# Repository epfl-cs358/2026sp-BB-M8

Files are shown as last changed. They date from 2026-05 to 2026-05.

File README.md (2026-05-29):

# 2026sp-BB-M8
<p align="center">
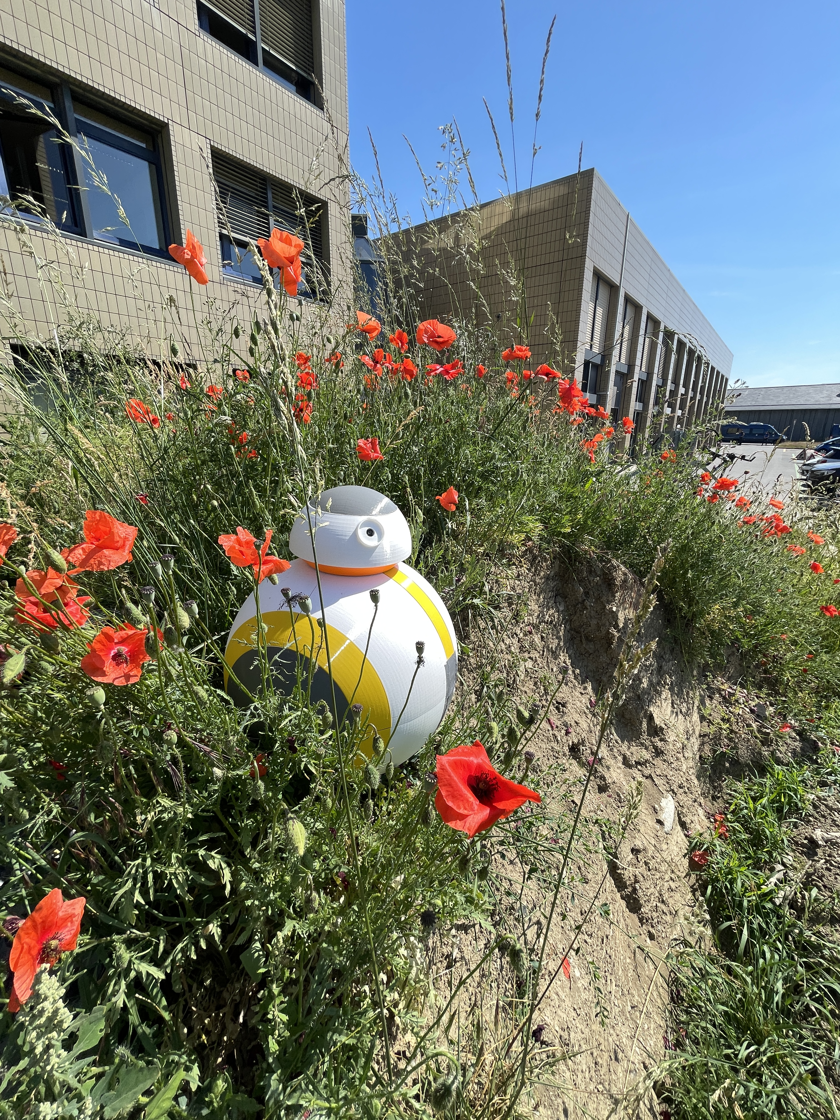
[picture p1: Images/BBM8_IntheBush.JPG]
  
</p>

## Contributors

* [Bernadette Orglmeister](https://github.com/boerniii)
* [Noa Cuccodoro](https://github.com/noa-ccdr)
* [Gaspard Héliot](https://github.com/gheliot)
* [Khadija Kammoun](https://github.com/khka5)
* [Gaël Diep](https://github.com/Damedane)
* [Jérôme Essola Elanga](https://github.com/Jess-lnga)

## Table of Content

- [2026sp-BB-M8](#2026sp-bb-m8)
  - [Contributors](#contributors)
  - [Table of Content](#table-of-content)
  - [Project overview](#project-overview)
    - [About the BB-M8](#about-the-bb-m8)
    - [List of Materials](#list-of-materials)
      - [Buy:](#buy)
      - [3D print:](#3d-print)
      - [Laser cut:](#laser-cut)
  - [Built the BB-M8](#built-the-bb-m8)
    - [Head](#head)
      - [Building the mechanical part:](#building-the-mechanical-part)
      - [Electronic Assembly of the head:](#electronic-assembly-of-the-head)
    - [Axis](#axis)
      - [Building the mechanical part:](#building-the-mechanical-part-1)
    - [Main Body](#main-body)
      - [Building the mechanical part:](#building-the-mechanical-part-2)
    - [Swinger](#swinger)
      - [Building the mechanical part:](#building-the-mechanical-part-3)
      - [Electronic Assembly of the swinger:](#electronic-assembly-of-the-swinger)
    - [Pole](#pole)
      - [Building the mechanical part:](#building-the-mechanical-part-4)
    - [Final assembly of the interior body](#final-assembly-of-the-interior-body)
      - [Building the mechanical part:](#building-the-mechanical-part-5)
      - [Electronic Assembly of the interior body:](#electronic-assembly-of-the-interior-body)
    - [Sphere](#sphere)
      - [Builting the sphere](#builting-the-sphere)
  - [Controlling the BB-M8](#controlling-the-bb-m8)
    - [Flashing the code](#flashing-the-code)
      - [Body (Wemos D1 R32 ESP32)](#body-wemos-d1-r32-esp32)
      - [Head (ESP32-CAM)](#head-esp32-cam)
      - [Uploading the dashboard (SPIFFS)](#uploading-the-dashboard-spiffs)
    - [Steering the BB-M8](#steering-the-bb-m8)
      - [Connecting](#connecting)
      - [Dashboard overview](#dashboard-overview)

## Project overview
### About the BB-M8
The BB-M8 is a spherical robot capable of moving across flat surfaces. This is achieved by means of an axis fitted with a pendulum, which can shift the centre of gravity, enabling the robot to navigate curves and maintain stability. The sphere also features a head, which is attached to the body by magnets and always remains on the upper surface of the sphere. The head is equipped with a camera and a rotating mechanism, allowing it to look in all directions. 

The BB-M8 can be connected to any computer via Wi-Fi and controlled from there via an interface, where you can also view the live feed from the camera.

Our BB-M8 is a replica of BB-8 from Star Wars.
The body has a diameter of approximately 35 cm, so a bit smaller than the original one.

### List of Materials
Here is an exhaustive list of all the elements needed to build the BB-M8. Note that you will need a 3D-printer with PETG filament to print some parts and a laser cutter.

#### Buy:
| Electronic Component | Model | Quantity |
|---|---|-----|
| Microcontroller | Wemos D1 R32 ESP32 | 1 |
| Microcontroller | AIThinker ESP32-CAM | 1 |
| Buck Converter | LM2596 | 2 |
| Stepper Motor | 28BYJ-48 | 1 |
| Motor Driver | ULN2003 | 1 |
| Servo Motor | DS3240 | 1 |
| Stepper Motor | NEMA 17 (17HS4401) | 1 |
| Motor Driver | TMC2208 | 1 |
| BMS 3S | HW-544 3S (11.1V/12.6V) BMS | 1 |
| BMS 2S | 2S 20A 18650 Lithium Battery Protection Board | 1 |
| LiPo | Conrad Energy 3S 11.1V 5000mAh | 1 |
| LiPo | LemonRC 2S 7.4V 350mAh | 1 |
| ON / OFF Switch | — | 2 | 
| Gearbox | 10:1 NEMA 17 gearbox | 1 |
| IMU | MPU-9250 | 1 |
| USB-to-TTL serial adapter | FTDI FT232R (HW-417-V1.2) | 1 |

| Other Parts | Specifications | Quantity |
|---|---|-----|
| Aluminium rod | 10 mm diameter, 310 mm length | 1 |
| Big Ball Bearings | 35 × 10 × 11 mm | 2 |
| Small Ball Bearing | 3 x 10 x 4 mm | 1 | <!-- TODO: What bearing is in the swinger -->
| Small Magnets | 5mm diameter, 4 mm height | 8 |
| Big Neodymium Magnets | 20 mm diameter, 12 mm height | 4 |
| Magnets for Bottom of Head | 14 mm diameter, 18 mm height | 4 |
| Wheels | 13 mm diameter | 4 |

- You will also need a **USB Isolator** to protect your computer and **data cables** to flash the code. 

- To charge the LiPos, you also need access to a **battery charging station**.
- Screws, nuts, heat-set inserts, jumpers and other basic supply is also needed, as well as tape and glue.

#### 3D print:
Here you can find all the [stl files](3D-Files/stl) that need to be printed with PETG filament. You find further information about the quantities in the specific subparts of building the BB-M8.

<!-- TODO: Uplode the stl file, and make a refernce to them -->

#### Laser cut:
The BB-M8 has also a few parts made of MDF. Here are the [dxf files](3D-Files/dxf). Note that you will need to use **different thicknesses** for the head and the body! Further information can be found in the corresponding section.
<!-- TODO: Uplode the dfx file, and make a refernce to them -->

## Built the BB-M8
Here are the instructions for building the BB-M8. Note that points having 🫟 in front of it, are further suggestions to make it cleaner and/or to remove unnecessary holes, for example, that are no longer needed.

Here you can find the [step file](3D-Files\FullAssembly.step) of the BB-M8.

### Head
<!-- TODO: Foto of the entire head -->
<!-- TODO: Describtion of the head and its functioning -->

https://github.com/user-attachments/assets/d43b33c3-5c80-41d6-bc25-aa63da8808fc

The head contains the ESP32-CAM with a camera and has an internal rotation mechanism, to make it turn. Another important aspect of the head is its iconic look and its size relative to the sphere, that makes our BB-M8 resemble the original one. 

<p align="center">
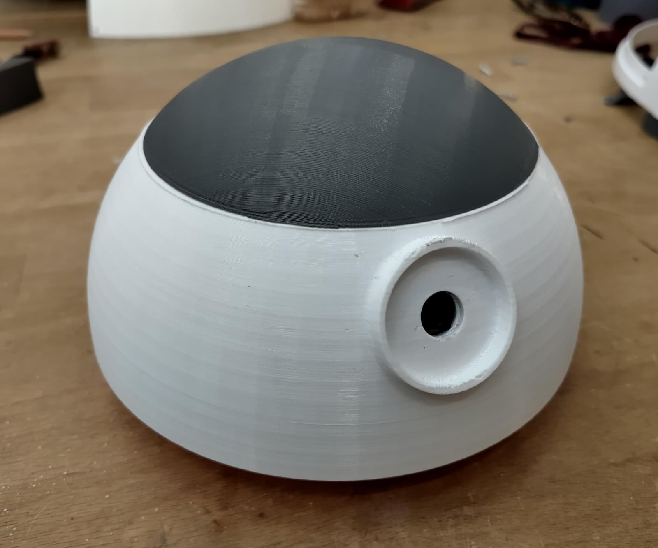
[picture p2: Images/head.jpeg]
  
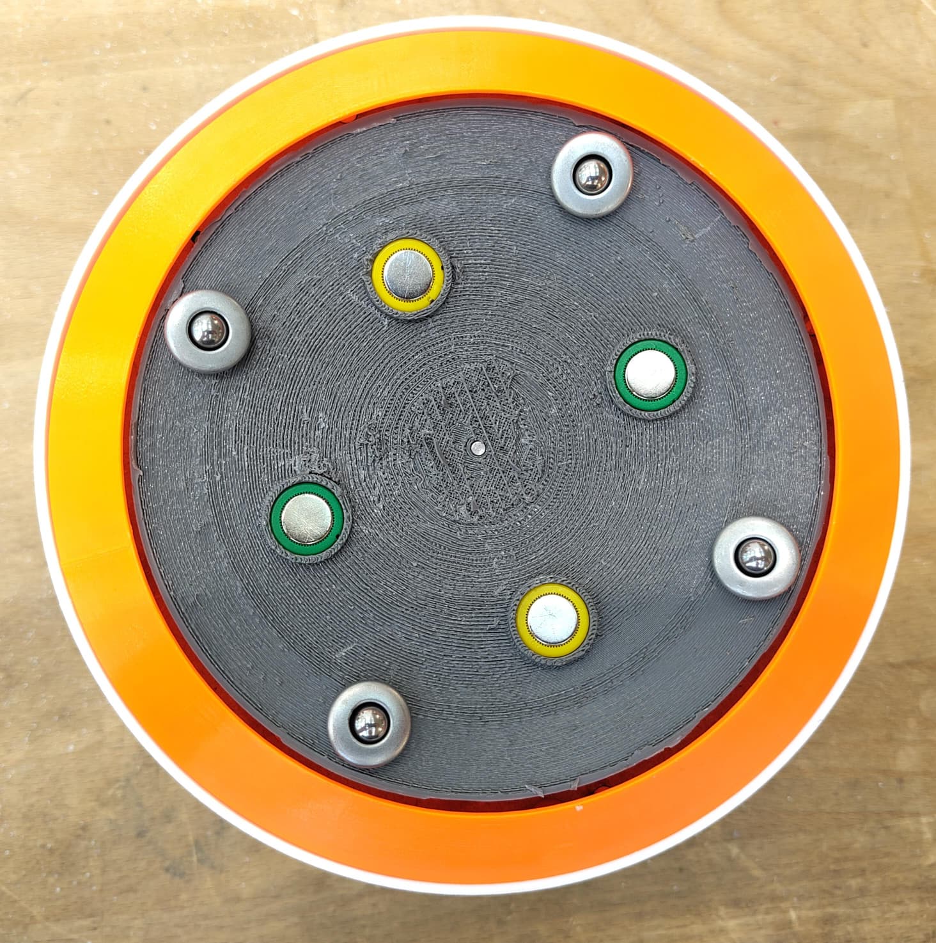
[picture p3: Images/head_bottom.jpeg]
  
</p>

#### Building the mechanical part:
The head is divided into different elements: the lid, the bottom plate (holding the magnets), the top plate (where the components are attached) and the manchette (hiding the bottom plate). 

1. Bottom plate:
    - Print the [bottom Plate](3D-Files/stl/Head_BottomPlate.stl) with PETG filament.
    - Add the **three heat-set inserts**.
    - Screw the [gear](3D-Files/stl/Head_GearBottomPlate.stl) to it.
    - Put the magnets and the wheels into the holes.
    - 🫟 The bottom plate and the gear can be printed in one piece. 

2. Lid: 
    - Print the [bottom of the lid](3D-Files/stl/Head_BottomPartLid.stl) and two times the [top of the lid](3D-Files/stl/Head_TopPartLid.stl).
    - Screw the two top parts together.
    - Then screw it to the rest of the lid.
    - Glue the small magnets into the holes. 
    - 🫟 The holes where the top is connected to the bottom do not perfectly line up, so if you want to have it more beautiful, change it.
    - 🫟 Theoretically, the lid could be printed in one piece with the front side of the ESP32 Holder directly attached to it. 

3. ESP32 Holder:
    - Print the two parts of the ESP32 Holder, [front](3D-Files/stl/Head_ESP32HolderFrontSide.stl) and [back](3D-Files/stl/Head_ESP32HolderBackSide.stl).
    - Add three heat-set inserts into the holes.
    - Then glue it into the lid, so that the holes for the camera line up.
     
4. Top Plate:
    - Laser cut the [top plate](3D-Files/dfx/Head_TopPlate.dxf) with the [stepper holder](3D-Files/dfx/Head_TopPlateStepper.dxf) and two times its [side](3D-Files/dfx/Head_TopPlateSides.dxf) using **4mm MDF**.
    - Glue the parts together.
    - Glue small magnets into the four holes at the edge.
    - Glue a small ball bearing into the hole in the middle, **pay attention that no glue drips into the bearing!**
    - Once the [electronic assembly](#electronic-assembly-of-the-head) is done, screw it onto the plate.
        - Make sure that the screws don't interfere with the magnets and wheels of the bottom plate.
        - Before attaching the stepper, make sure to print and add the [gear](3D-Files/stl/Head_GearForStepper.stl) and also depending on the size of the screw head, carve the edges so that they are not in the way of the gear.
    - Add a bit of velcro to the LiPo and the counterpart to the plate.

5. Final Assembly:
    - Print and then glue the [ball bearing stopper](3D-Files/stl/Head_BallBearingStopper.stl) to a small rod (that fits the ball bearing perfectly). Then slide it through the ball bearing and into the gear of the bottom plate, line it up with the other gear and then attach it with a screw. 
    - 🫟 The attachment of the bearing can be done more properly by using rings and creating a shaft. <!-- TODO: Better explenation -->

6. Manchette:
    - Print the [manchette](3D-Files/stl/Head_Manchette.stl)
    - Add four M2.5 heat-set inserts into the four holes.
    - Screw it to the top plate.

Now the head can be easily opened and closed with the magnets!

<p align="center">
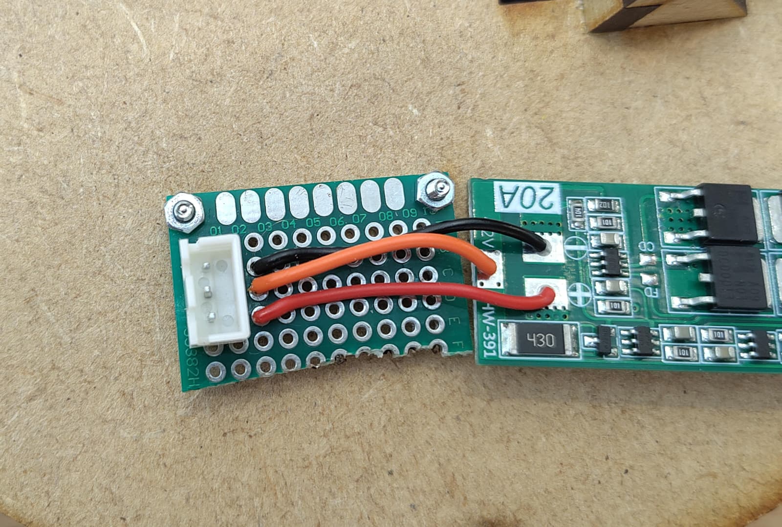
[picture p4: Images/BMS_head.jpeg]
    
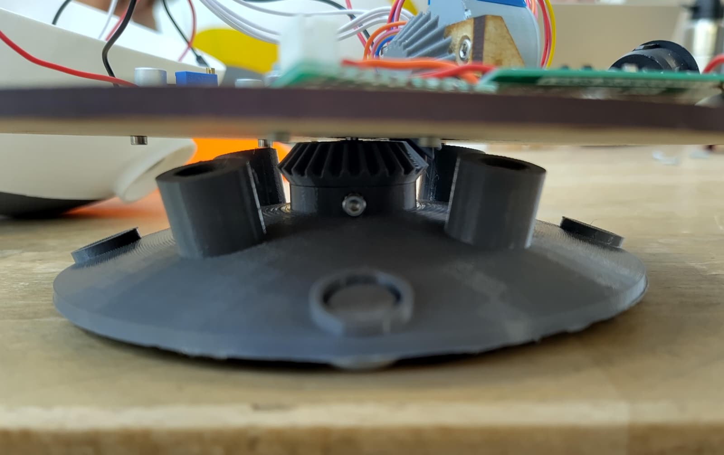
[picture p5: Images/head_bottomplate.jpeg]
    
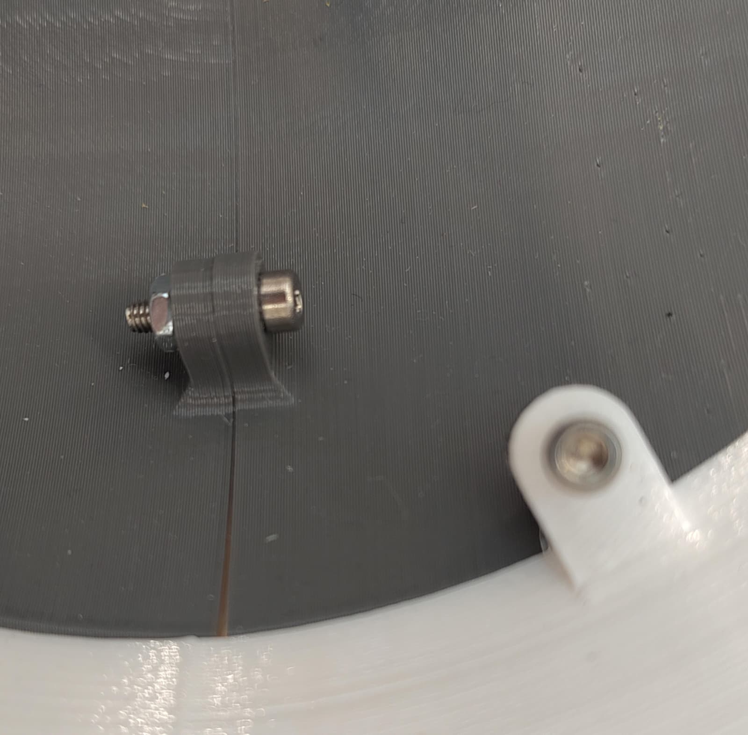
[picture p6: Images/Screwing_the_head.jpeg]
    
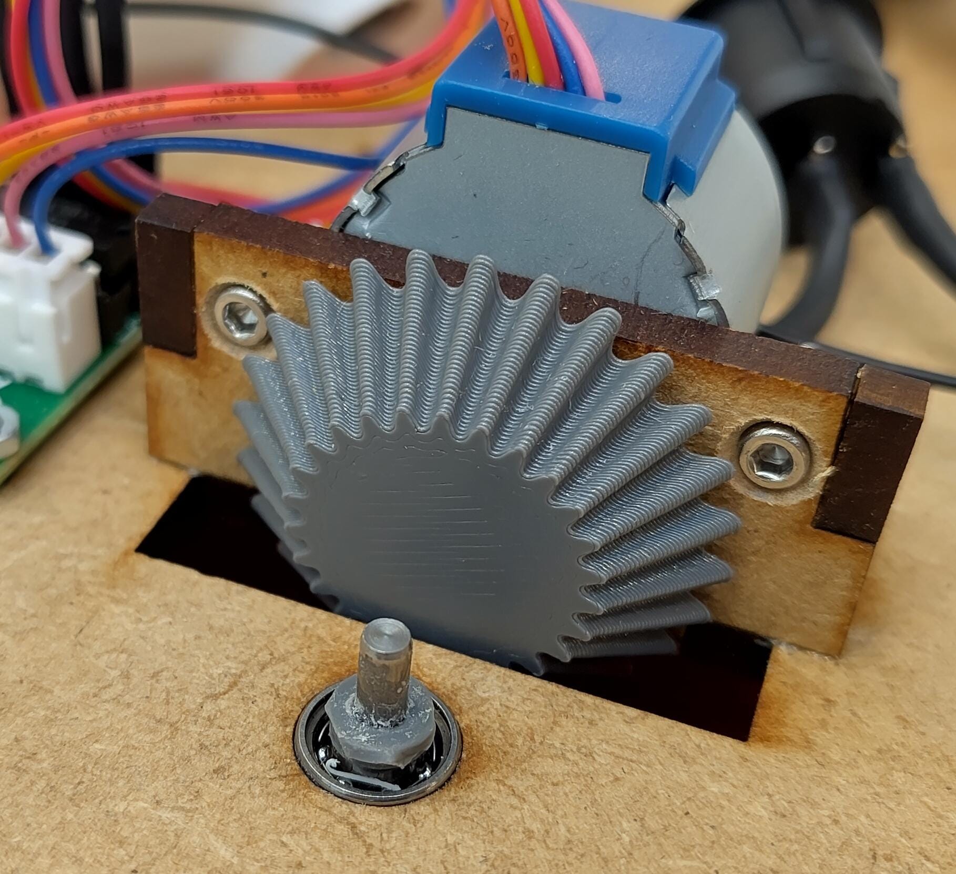
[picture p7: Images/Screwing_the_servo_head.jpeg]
    
</p>

<p align="center">
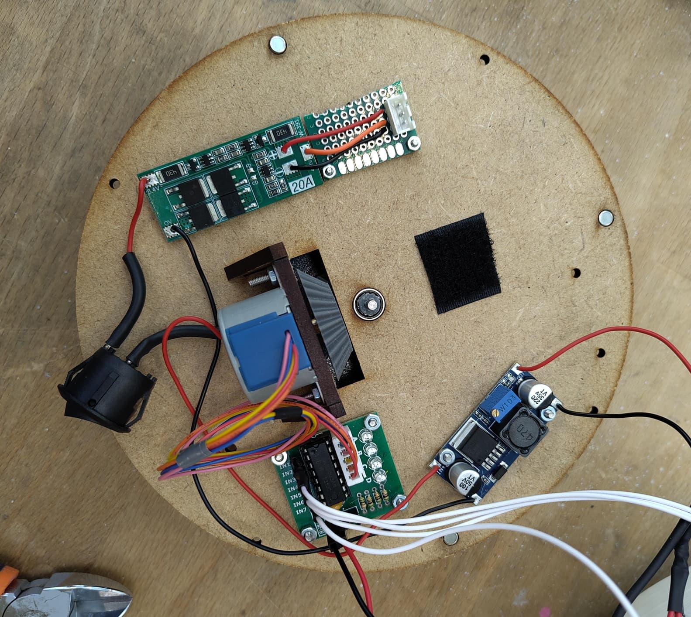
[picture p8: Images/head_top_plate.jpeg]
    
    <!-- TODO: Image of the inside of the lid with EPS32 CAM-->
</p>

<!-- TODO: Continue-->

#### Electronic Assembly of the head:

<p align="center">
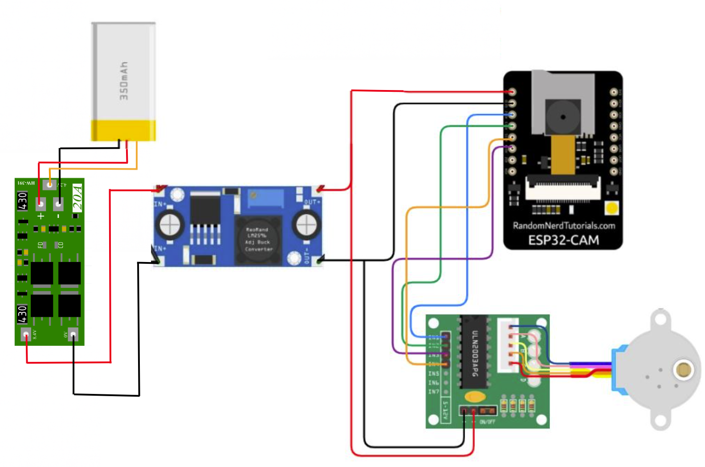
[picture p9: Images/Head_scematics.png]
    
</p>

1. Calibrate the **buck converter to 5V**.
2. Solder the connector of the LiPo to the BMS and make sure that it works correctly.
3. Connect the components as in the schematic above. 
    - Make sure that the **cables connecting the ESP32-CAM are long** enough to easily open the lid of the head. 

### Axis
The Axis is the part that will transmit the rotation from the stepper to the sphere. It is made of aluminium to make sure it doesn't bend, it also holds a gear that should be making the axis turn, 2 bearings that will hold the main body and avoid friction, 4 stop rings that will make sure the bearings stay in place, and the box doesn't slip out of the bearing, and finally a junction in 2 parts that will be the attachment of the axis to the body.  

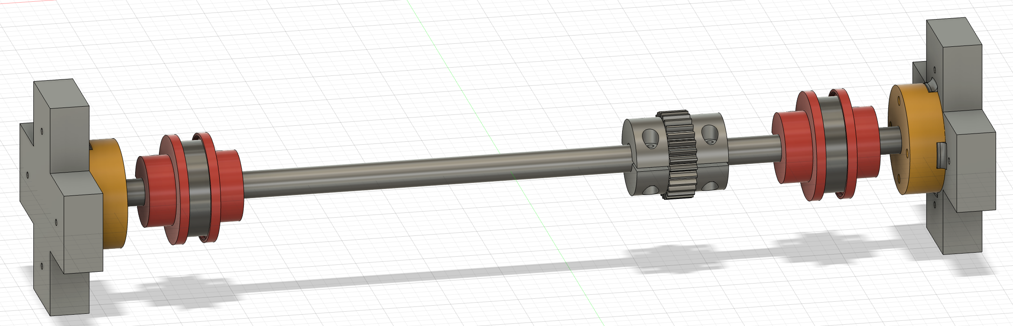
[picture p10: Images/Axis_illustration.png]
Axis Illustration


https://github.com/user-attachments/assets/9146e50d-00f2-4c6c-8933-5cecaacd3a80

#### Building the mechanical part:
The axis is divided into different elements: the rod, the gear, the bearings, the stop rings, the first junction, and the second junction. 

1. Rod:
    - Get yourself a 310mm aluminium rod with diameter 10.
    - Drill holes and thread them with a lathe at the two ends of the rod for M2.5 Screws. The holes should be around 5mm deep.
    - Make a 10mm D shape that is 1mm deep at the 2 ends, and make sure the 2 ends have D shapes facing the exact same direction.
    - 🫟 The deepness of the holes, and the length of the D shapes can be a bit bigger and it will totally work. Just don't make them smaller.
    - 🫟 If you need visual support, [here](3D-Files/stl/Axis_Rode.stl) is an STL file, but DO NOT PRINT IT, it won't be resistant enough!  

2. Gear: 
    - 3D Print the [gear](3D-Files/stl/Axis_GearMainPart.stl) and two times the [second part of the gear](3D-Files/stl/Axis_GearSecondPart.stl).
    - Add 4 M2.5 heat-set inserts.
    - With 4 M2.5x16 screws and 4 M2.5 nuts, tighten the gear around the axis.
    - 🫟 For now do not tighten them to the max so that you can easily move it around and find the right position once the main body is done.
    - 🫟 Keep in mind that all the axis will have to be disassembled and reassembled into the actual main body, so this is just to test and make sure all parts work.

3. Bearings:
    - Buy two bearings of size 35x10x11.
    - You'll put them on the rod on each side after adding the two first stop rings (next step).
     
4. Stop rings:
    - 3D print 4 times the [stop rings](3D-Files/stl/Axis_StopRing.stl).
    - Add 4 M2.5 heat-set inserts.
    - With 4 M2.5x16 screws and 4 M2.5 nuts, tighten the stop rings around the axis.
    - Remember to follow the first screenshot to put everything in the right order.

5. First junction:
    - 3D print 2 times the [first junction](3D-Files/stl/Axis_JunctionWithSphere.stl).
    - Put it in the D shape of each end, and screw it to the rod with an M2.5x10.
    - 🫟 If you cannot find a screw that perfectly tightens the junction, just add nuts until it has the desired length (and vary the length of the screw). 

6. Second junction:
    - 3D print 2 times the [second junction](3D-Files/stl/Axis_JunctionToJunction.stl).
    - Just clip it on the first junction.

Now the Axis is done, you'll have to disassemble it and reassemble it in the main body once you're sure each component of the axis is well made!

### Main Body
The main body is essentially a wooden box with a few holes to put a Servo, and has the important duty to hold the axis, the NEMA, the pole for the head, and the swinger. It is the centrepiece of the project.  
<p align="center">
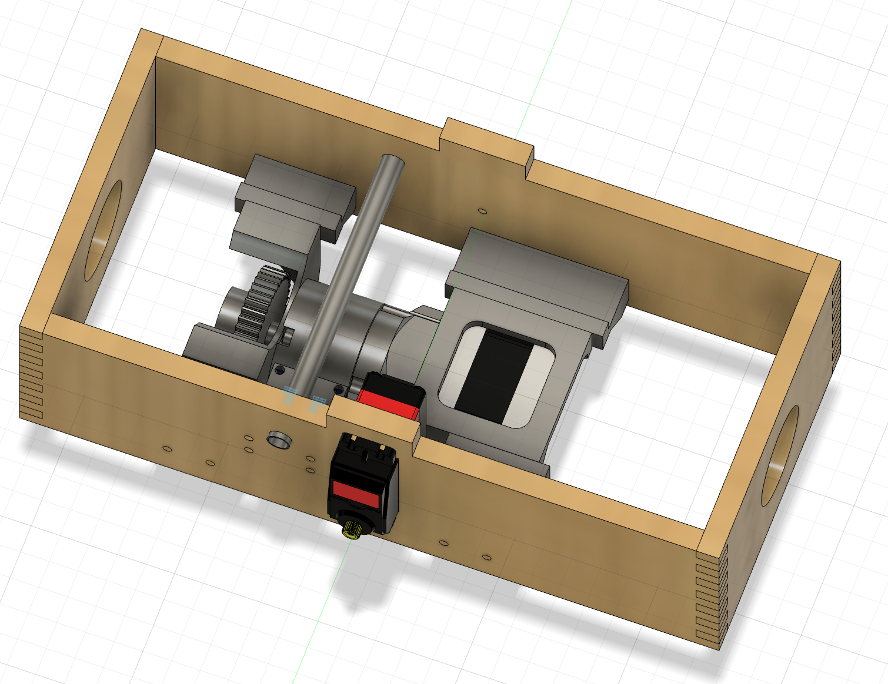
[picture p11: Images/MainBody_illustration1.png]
    
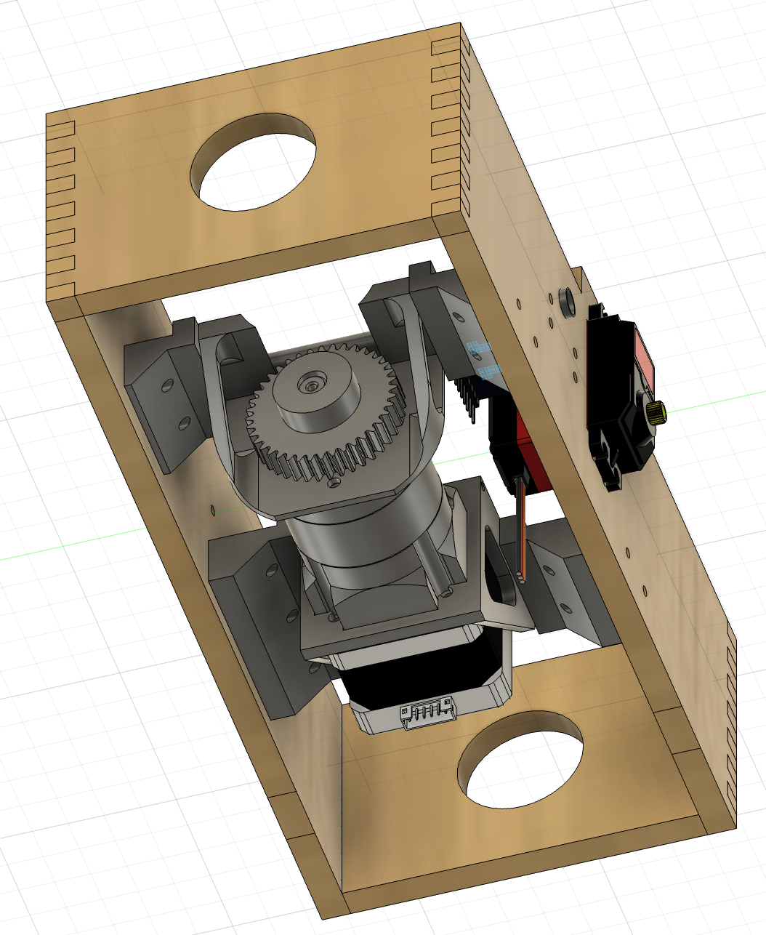
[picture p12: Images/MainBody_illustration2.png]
    
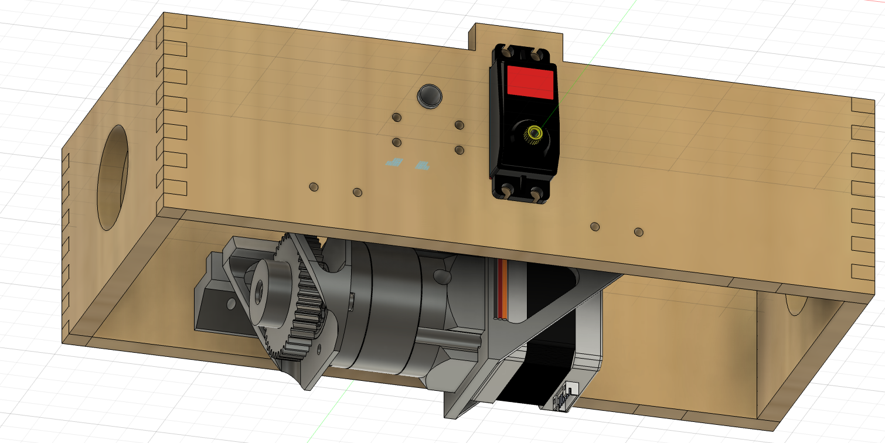
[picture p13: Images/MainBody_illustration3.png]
    
</p>

https://github.com/user-attachments/assets/4a70eb73-42a0-409a-afb2-720c48bfd937

#### Building the mechanical part:
The main body is divided into multiple parts: the box, the IMU holder, the two NEMA holders, the stepper and its gearbox, the gear on the gearbox shaft, the Servo, and the pin that holds the second arm of the swinger.

1. Box:
    - On an 8mm thickness sheet of MDF, laser cut one [Large side](3D-Files/dxf/SideBoxLarge.dxf), one [Large side with servo](3D-Files/dxf/SideBoxLargeServoHole.dxf), and two [Sides with holes for axis](3D-Files/dxf/SideBoxWithHoleForAxis.dxf).
    - Then be careful to glue everything together with 90° angles (easier said than done!).

2. IMU holder: 
    - 3D print the [IMU holder](3D-Files/stl/MainBody_IMUHolder.stl).
    - Put it into place with 2 M3x10 screws and 2 M3 nuts. 

3. NEMA holders:
    - 3D print one [NEMA holder Servo side back](3D-Files/stl/MainBody_NemaHolderAttachementServoSide.stl), one [NEMA holder Cap side back](3D-Files/stl/MainBody_NemaHolderAttachementCapSide.stl) and one [NEMA holder](3D-Files/stl/MainBody_NemaHolder.stl). All of these three will attach the NEMA to the center of the box. First assemble this.
    - Then the next three parts are going to prevent the NEMA's shaft from bending and losing the contact between the two gears.
    - 3D print two [NEMA holder front](3D-Files/stl/MainBody_NemaHolderShaft.stl) and one [NEMA holder front screwed](3D-Files/stl/MainBody_NemaHolderScrewed.stl). Assemble these last three pieces together. 
     
4. Stepper & Gearbox:
    - Assemble the NEMA 17 with the Gearbox, and make sure the NEMA Shaft is tightened on the gearbox input.
    - Assemble the NEMA 17 with the NEMA holders using 9 M2.5x10 for the holders themselves, and 9 M3x12 to connect the holders on the MDF box.
    - 🫟 Make sure the socket of the NEMA is looking down.
  
5. Gear shaft:
    - 3D print this [gear](3D-Files/stl/MainBody_GearShaft.stl), make sure you put at least 90% infill to avoid an embarrassing breaking of the gear.
    - Put the gear on the shaft of the gearbox and screw an M3x16 screw with an M3 nut that you're going to fit in the hole extruded for it.

6. Servo:
    - Add the Servo in its hole. Make sure its cables are looking down. 
    - Screw it with 4 M3x12 screws and 4 M3 nuts.  

7. Pin:
    - Buy a pin that is 3mm diameter and 40mm long.
    - Put it inside the hole that is facing the Servo on the opposite side of the box.
    - 🫟 This pin will hold the second arm of the Swinger. 

Now the Main Body is done, let's build the Swinger!

### Swinger
The Swinger is a very technical part; it'll hold all the electronics, and swing thanks to the Servo to make the BB-M8 turn and balance. 

<p align="center">
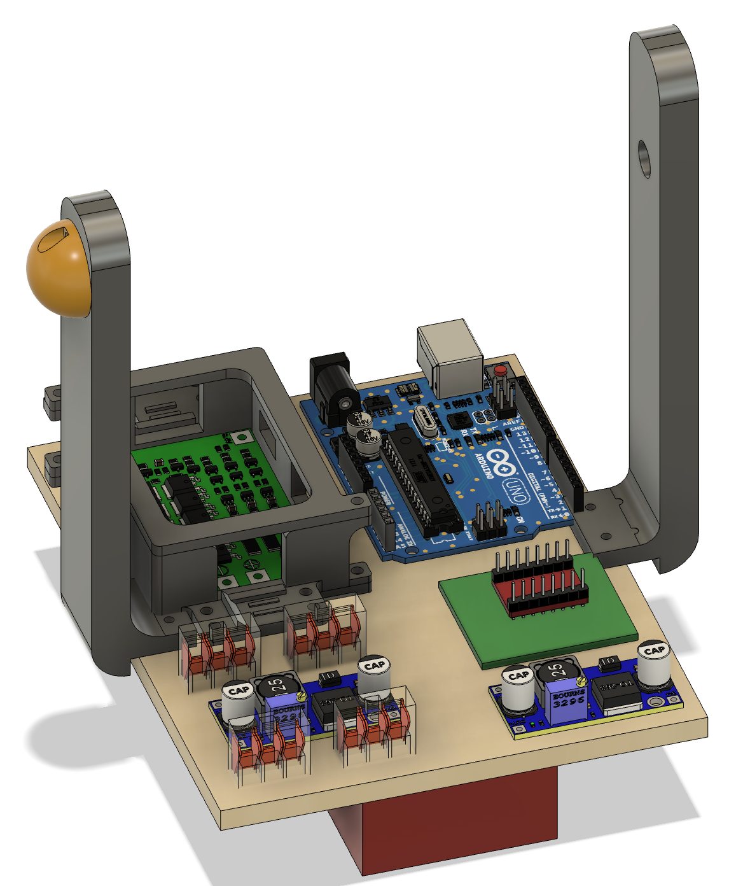
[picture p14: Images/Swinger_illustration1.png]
    
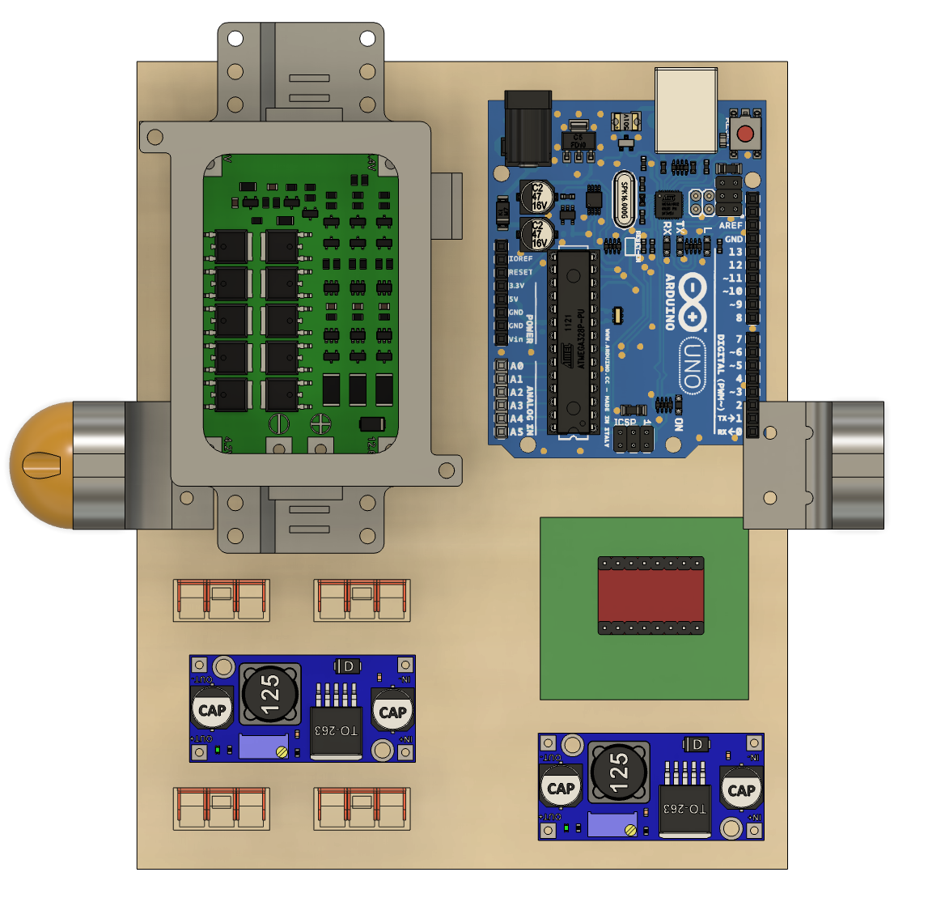
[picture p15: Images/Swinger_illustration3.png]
    
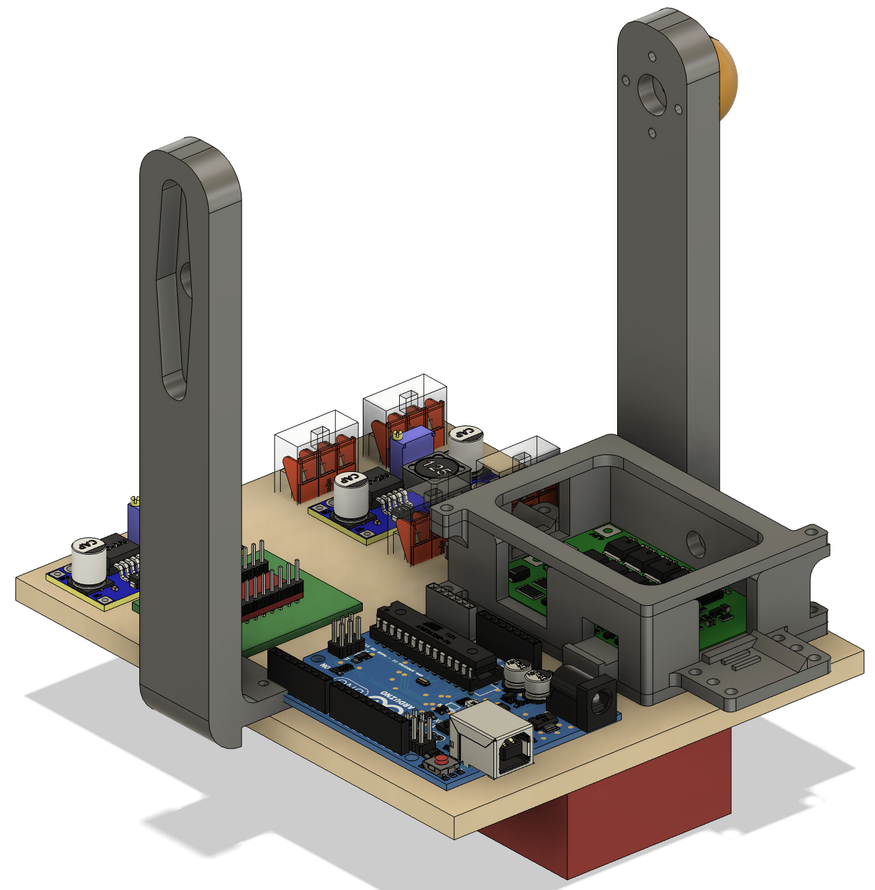
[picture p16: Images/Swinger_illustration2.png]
    
</p>

https://github.com/user-attachments/assets/8d093857-c81f-4bc1-969b-20ae95724053

#### Building the mechanical part:
The Swinger is essentially a rectangular MDF sheet with holes to screw all the electronics, velcro under to stick the LiPo, and arms to connect to the main body. It will hold the BMS inside a BMS box, the 2 buck converters, the ESP32, the NEMA's driver, and some wago.

1. MDF Sheet
   - On a 6mm MDF plate, Laser cut this [sheet](3D-Files/dxf/Swinger_Sheet.dxf).
2. BMS Box
   - 3D print the [BMS Box](3D-Files/stl/Swinger_BMSBoxBox.stl) and its [Bottom](3D-Files/stl/Swinger_BMSBoxBottom.stl).
   - After soldering the cables and connectors, put the BMS inside the Box, and screw the box and bottom to the MDF sheet with 2 M2.5x10 screws.
3. Arms
   - 3D print the [Servo arm](3D-Files/stl/Swinger_ArmServo.stl) and the [Cap arm](3D-Files/stl/Swinger_ArmBearing.stl).
   - In the servo arm, put the Servo horn that fits the extruded shape.
   - In the Cap arm, add a 10x3x4 bearing in the extruded cylinder shape.
   - Screw the 2 arms with 2 M2.5x12 and 2 M2.5 nuts for each arm on the sheet of MDF.
4. Cap 
   - 3D print the [Cap](3D-Files/stl/Swinger_ArmCap.stl).
   - Screw it with 2 M2.5x12 and 2 M2.5 nuts on the Cap arm.
5. LiPo
   - Put some velcro under the Swinger and on the LiPo to make them stick. 
6. Weight
   - Add the weight around the LiPo by hot-gluing it.
7. Electronic components
   - Add all the electronic components on the MDF sheet and make sure they are well screwed.
   - 🫟 Remember that the LiPo is right under the electronic components, therefore, there shouldn't be any screws sticking too much out to avoid damaging the LiPo.

#### Electronic Assembly of the swinger:
<p align="center">
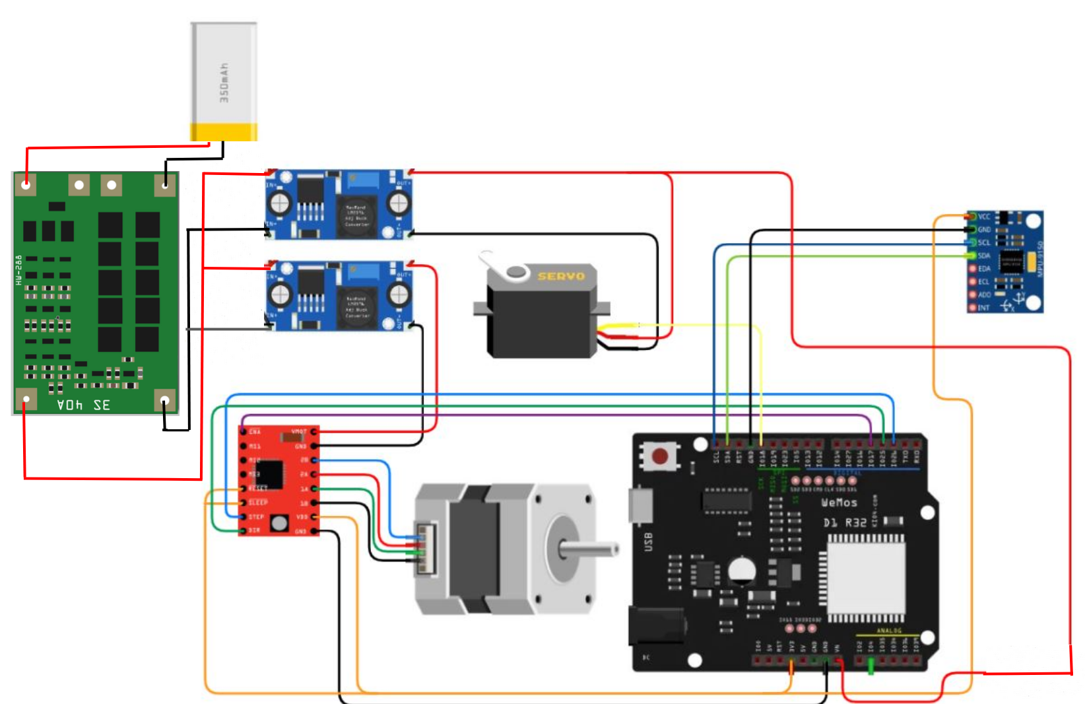
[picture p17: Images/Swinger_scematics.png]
    
   </p>

The swinger hosts all the body electronics. Connect the components as follows:

1. **Power distribution:**
    - The LiPo (3S 11.1V) connects to the BMS, then through the ON/OFF switch to the rest of the circuit.
    - **Buck converter 1** (set to **6V**) → servo DS3240 only.
    - **Buck converter 2** (set to **5V**) → Wemos D1 R32 + TMC2208 driver + IMU.
    - Keeping the servo on its own buck converter prevents it from stealing current from the ESP32 when it moves.

2. **Wemos D1 R32:**
    - Connect the TMC2208 STEP and DIR pins to the dedicated GPIO pins (GPIO 25 and GPIO 26).
    - Connect the servo signal wire to GPIO 18.
    - Connect the IMU (MPU-9250) via I²C: SDA → GPIO 21, SCL → GPIO 22.

3. **NEMA 17:**
    - Connect the four motor wires to the TMC2208 driver outputs.

> Make sure the GND of all components is shared, even across the two buck converters, otherwise the servo PWM signal will not work correctly.

### Pole
The pole is the part that sticks from the main body to hold magnets that will attach the head. 

#### Building the mechanical part:
The pole is divided into three elements: the body attachment, the pole and the magnets holder.

1. Body attachment
   - 3D print the [body attachment](3D-Files/stl/Poll_BodyAttachement.stl), and put an M2.5 heat-set insert inside the hole.
   - Add an M2.5x12 screw.
2. Pole 
   - Cut a 20mm diameter pipe to 135mm (use a pipe type, not a solid rod, the goal is to avoid putting too much weight high up).
3. Magnets holder
   - 3D print the [magnets holder](3D-Files/stl/Poll_MagnetHolder.stl), put an M2.5 heat-set insert inside the hole, then add the M2.5x12 screw.
   - Put the magnets inside, then tape them, and put some hot glue on the back to avoid having the magnets escaping.

### Final assembly of the interior body
Now that you've successfully built each part of the interior of the body successfully, it's time to assemble them.

#### Building the mechanical part:
1. Axis & Main body 
   - Slide the Axis into the Main body, and, when half way sliding it, add all the components of the axis that will be inside the box.
   - It may be slightly difficult to correctly align the two gears, but it is perfectly normal.
   - Make sure to tighten all the screws very well (without breaking the inserts).
<p align="center">
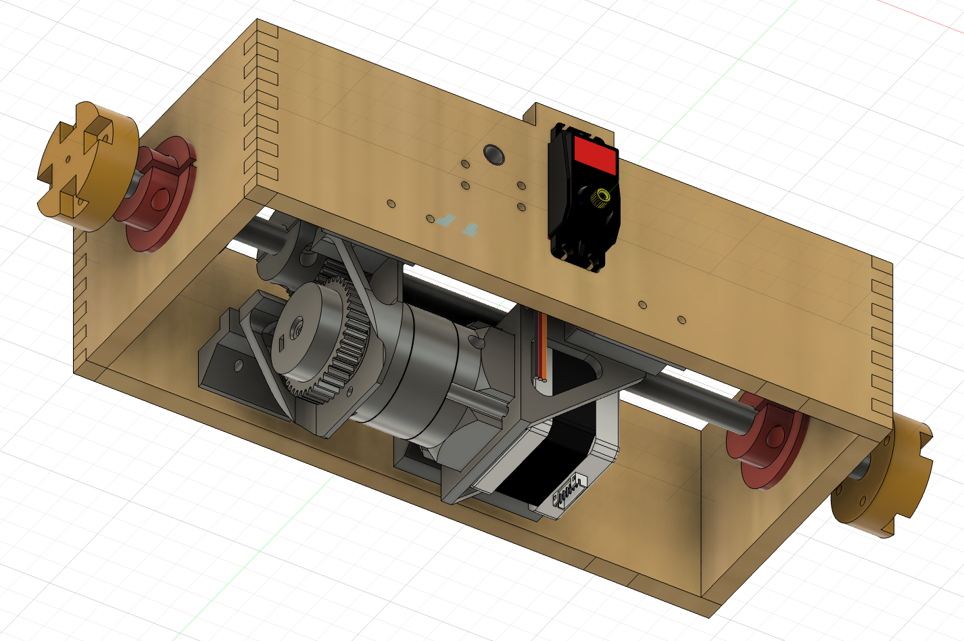
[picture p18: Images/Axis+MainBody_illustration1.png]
    
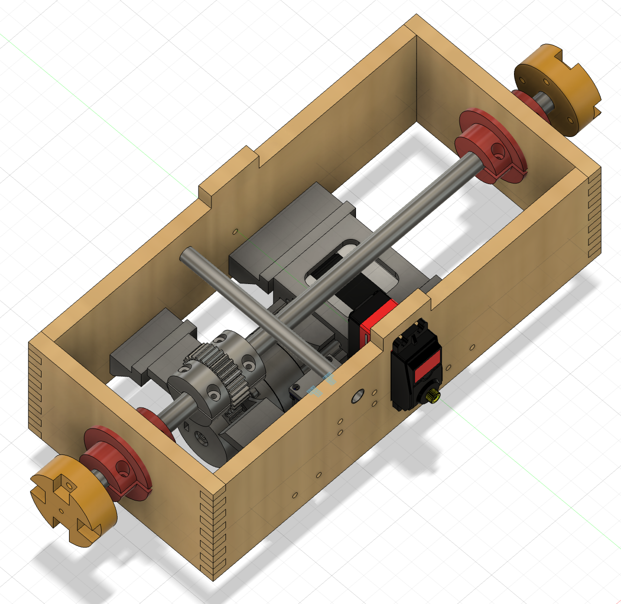
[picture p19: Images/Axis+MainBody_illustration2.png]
    
</p>
2. Pole
   - Screw the whole pole part to the main body with 4 M2.5x12 screws and 4 M2.5 nuts.
3. Swinger 
   - Connect now the swinger with the rest by clipping the Servo into its horn, and secure it with its screw, and on the other side, slide the pin through the arm cap, and through its bearing.
<p align="center">
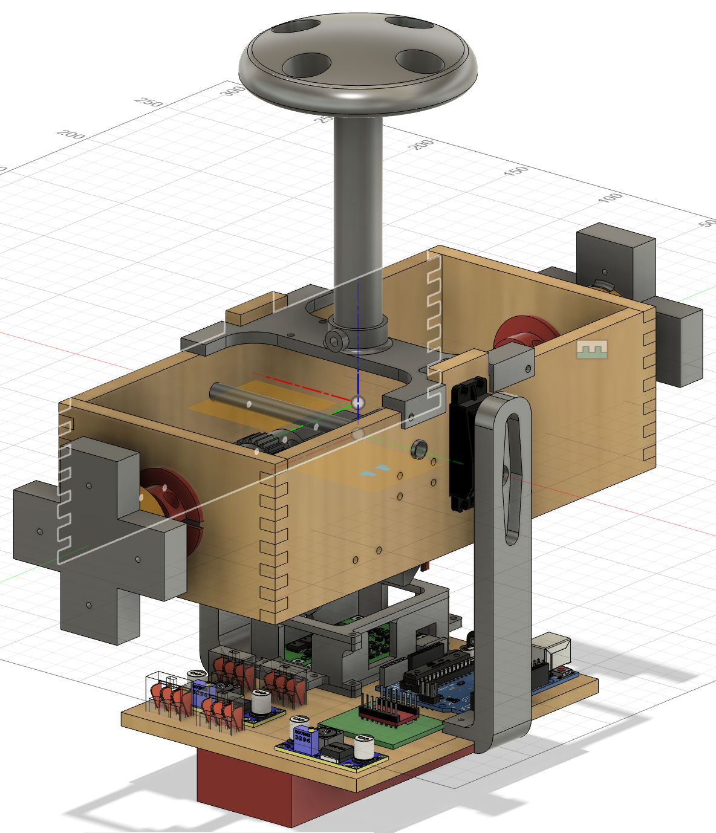
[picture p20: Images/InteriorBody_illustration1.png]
    
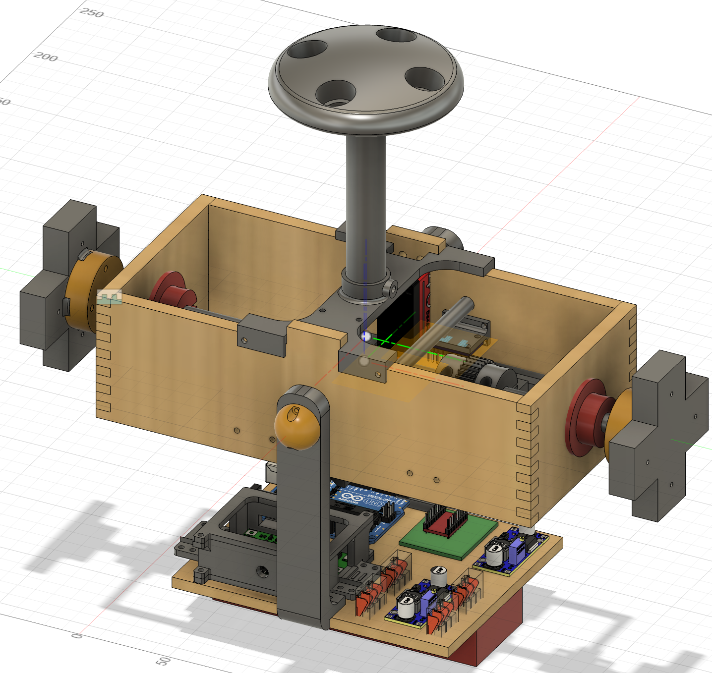
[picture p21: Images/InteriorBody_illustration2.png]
    
</p>

#### Electronic Assembly of the interior body:
1. Servo 
   - Connect the Servo to its dedicated wires.
2. IMU
   - Connect the IMU to its dedicated wires.
3. NEMA
   - Connect the NEMA to its dedicated wires.
4. Cable management
   - Make sure the electronics in the swinger doesn't touch the gear on the shaft of the gearbox at any position of the swinger  

You now have the whole interior body. All that's left is to put it inside the sphere, and... voilà!

### Sphere

https://github.com/user-attachments/assets/a65b6fe3-ab26-49d3-bca7-5c9b17b3753b

The sphere itself is 3D-printed in multiple smaller parts so that it can easily be printed on a normal sized Prusa. You need to print the following parts in PETG filament:

| stl file | Quantity |
|---|---|
| [caps](3D-Files/stl/Sphere_Cap.stl) | 2 |
| [bones](3D-Files/stl/Sphere-Bone.stl) | 8 |
| [equator piece](3D-Files/stl/Sphere_Equator.stl)| 4 |
| [top yellow piece](3D-Files/stl/Sphere-TopYellowPart.stl) | 8 |
| [white parts](3D-Files/stl/Sphere_WhitePart.stl) | 6 |
| [opening lid](3D-Files/stl/Sphere_Lid.stl) | 2 |
| [lid surrounding](3D-Files/stl/Sphere_LidSurrounding.stl) | 2 | 

#### Builting the sphere
 1. 3D-Print all the parts.
 2. Glue the pieces together with hot glue.
    - It is important to keep **1/4 open** so that the inner body still can be placed inside.
    - **Do not** glue the caps to the rest of the sphere. 
 
3. Place the [main body](#main-body) inside and make sure that it has enough space.
4. Put the second cap on top, close the last part and attach it with tape.

<p align="center">
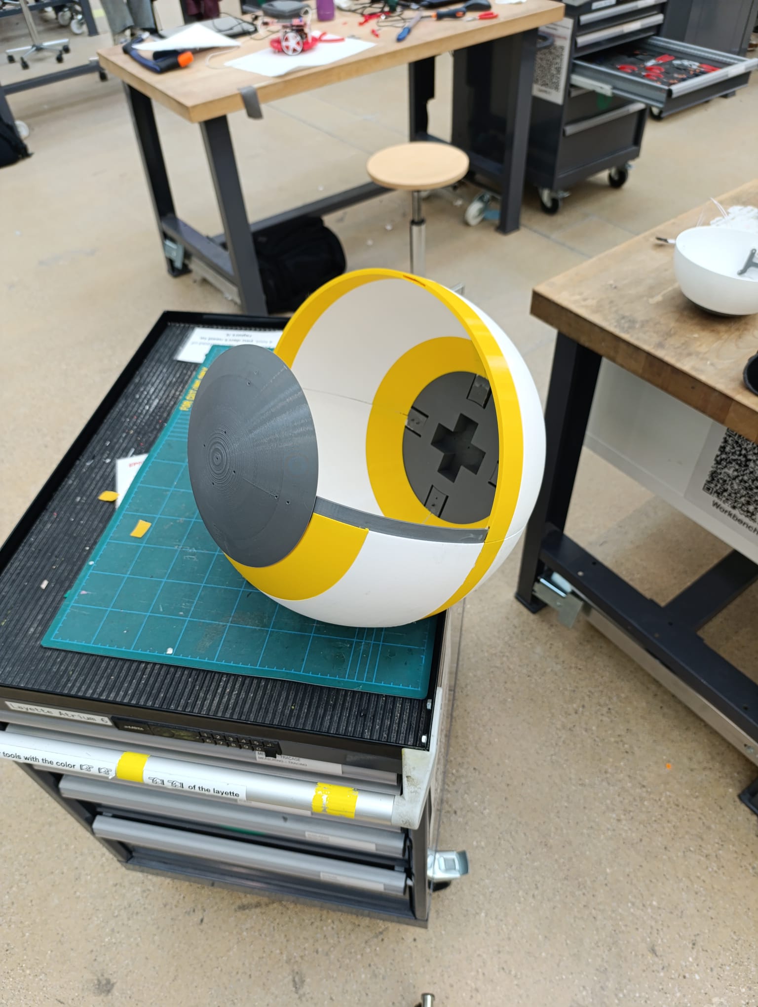
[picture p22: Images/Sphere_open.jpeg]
    
</p>

## Controlling the BB-M8

### Flashing the code

You will need [PlatformIO](https://platformio.org/) installed in VS Code to flash both microcontrollers.

#### Body (Wemos D1 R32 ESP32)

The Wemos has a native USB port — no adapter needed.

1. Connect the Wemos to your computer via USB.
2. Open the `BBM8_body` folder in VS Code with PlatformIO.
3. Click **Upload** or run `pio run --target upload` in the terminal.

#### Head (ESP32-CAM)

The ESP32-CAM has no native USB port. You need a **FTDI FT232R USB-to-TTL adapter** to flash it.

**Wiring (FTDI → ESP32-CAM):**

| FTDI | ESP32-CAM |
|---|---|
| TX | U0R (RX)  |
| RX | U0T (TX)  |
| 5V | 5V |
| GND  | GND |

Also connect **IO0 → GND** on the ESP32-CAM to enable flash mode. **Remove this wire after flashing.**

1. Wire the FTDI to the ESP32-CAM as above.
2. Open the `BBM8_head` folder in VS Code with PlatformIO.
3. Click **Upload**. When you see `Connecting......` in the terminal, press the **RST** button on the ESP32-CAM.
4. Once the upload is complete, disconnect IO0 from GND and press RST again.

#### Uploading the dashboard (SPIFFS)

The web dashboard (`BBM8_head/data/index.html`) is stored on the ESP32-CAM's filesystem and must be uploaded separately from the code.

1. Keep the FTDI connected.
2. In VS Code with PlatformIO, run **Platform → Upload Filesystem Image**, or run `pio run --target uploadfs` in the terminal.
3. The dashboard will now be served at `http://192.168.4.1` every time the head powers on.

---

### Steering the BB-M8

#### Connecting

1. Power on the BB-M8.
2. On your computer or phone, connect to the Wi-Fi network **`BBM8`** (password: `starwars`).
3. Open a browser and navigate to **`http://192.168.4.1`**.

#### Dashboard overview

**Camera feed**
Click **FEED ON** in the top-right corner of the camera panel to start the live FPV stream.

**Movement**
Use the **virtual joystick** to drive BB-M8 — the Y axis controls forward/backward speed, the X axis controls steering. The **arrow keys** on your keyboard work as well.

**Telemetry**
The bottom panel shows 7 live graphs updated at 10 Hz: Roll, Pitch, Drive Speed, PID Output, PID Error, Integral and Derivative.

**PID tuning**
Adjust Kp, Ki, Kd in the right panel and click **Apply Gains** to send them to the robot without reflashing. Starting values: Kp = 0.9, Ki = 0.05, Kd = 0.1.

**Target Roll / Target Speed**
Send a fixed value directly to the robot independently of the joystick. Useful for calibration.

**Safety**
The **STOP** button immediately halts the robot. Click **RESUME** to re-enable.　The robot starts in STOPPED mode for safety reasons.

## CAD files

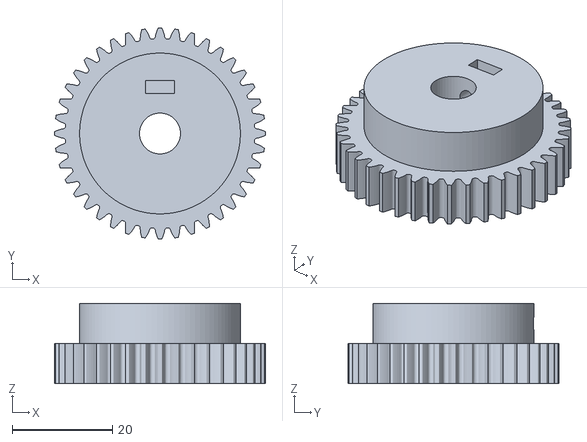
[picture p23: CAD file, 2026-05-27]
3D-Files/stl/MainBody_GearShaft.stl
42.0 x 42.0 x 16.0

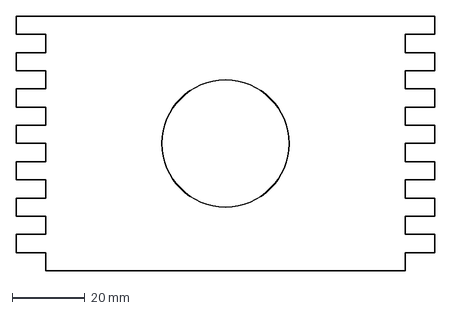
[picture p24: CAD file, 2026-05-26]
3D-Files/dxf/MainBody_SideBoxWithHoleForAxis.dxf
115.0 x 70.0 mm

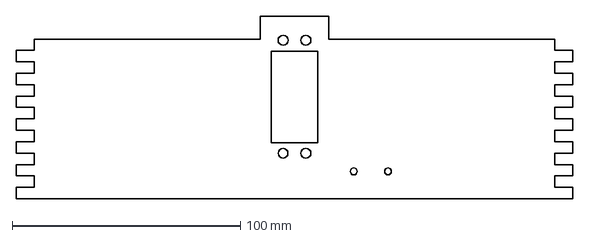
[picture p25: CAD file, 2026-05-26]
3D-Files/dxf/MainBody_SideBoxLargeServoHole.dxf
244.0 x 80.0 mm

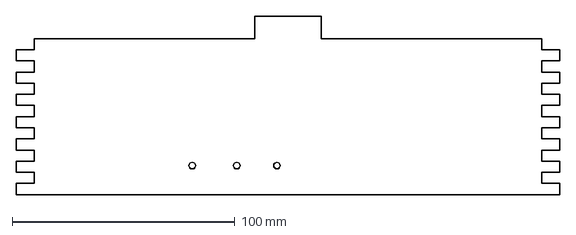
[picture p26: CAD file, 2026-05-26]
3D-Files/dxf/MainBody_SideBoxLarge.dxf
244.0 x 80.0 mm

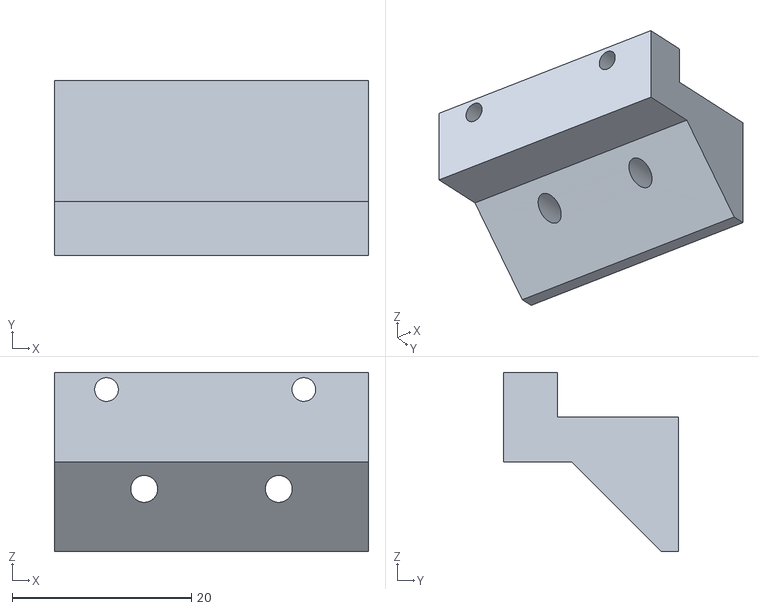
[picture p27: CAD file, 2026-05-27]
3D-Files/stl/MainBody_NemaHolderShaft.stl
35.0 x 19.5 x 20.0

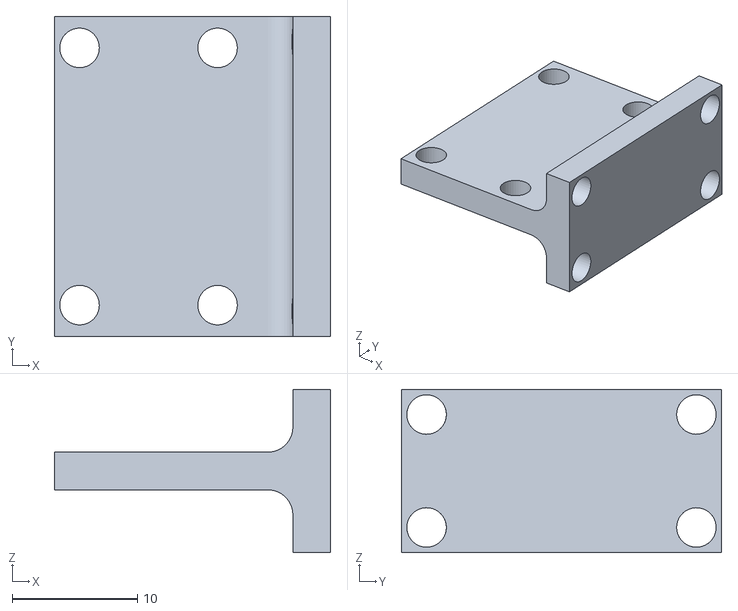
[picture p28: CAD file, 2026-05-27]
3D-Files/stl/MainBody_IMUHolder.stl
22.0 x 25.5 x 13.0

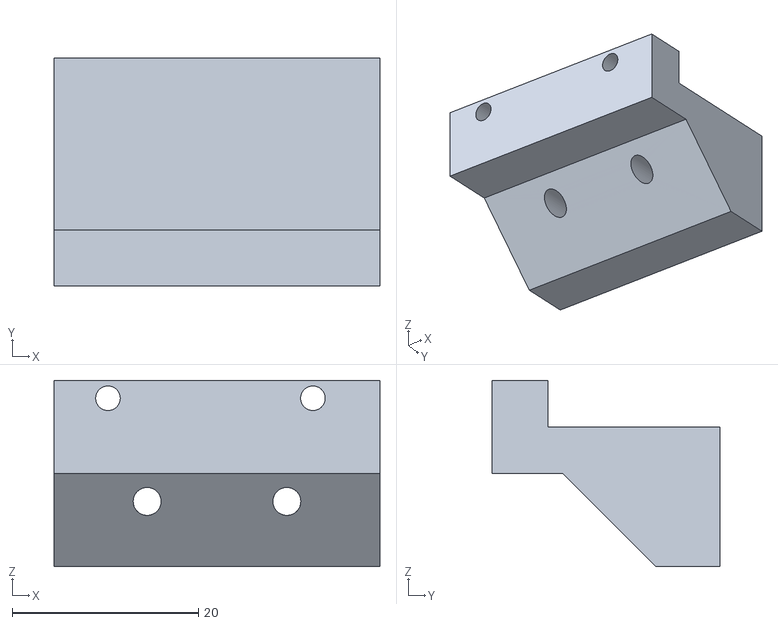
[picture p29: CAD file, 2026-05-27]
3D-Files/stl/MainBody_NemaHolderAttachementServoSide.stl
35.0 x 24.5 x 20.0

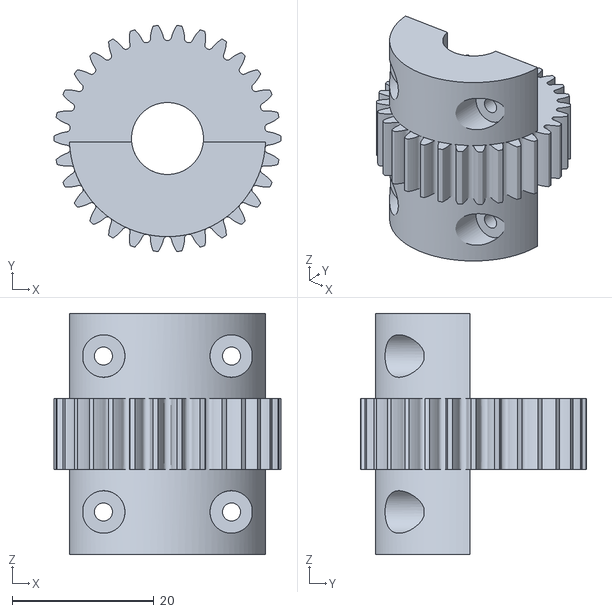
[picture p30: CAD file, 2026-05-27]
3D-Files/stl/Axis_GearMainPart.stl
32.0 x 31.9 x 34.0

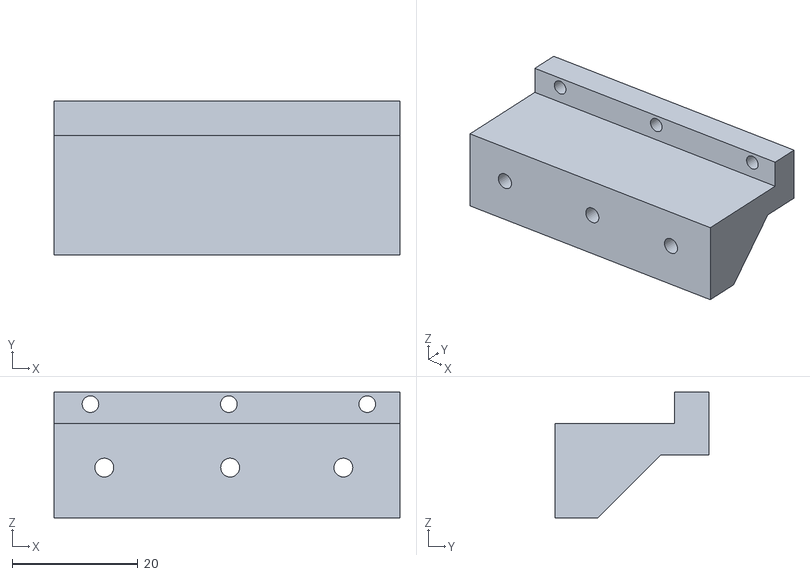
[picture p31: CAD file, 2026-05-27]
3D-Files/stl/MainBody_NemaHolderAttachementCapSide.stl
55.0 x 24.5 x 20.0

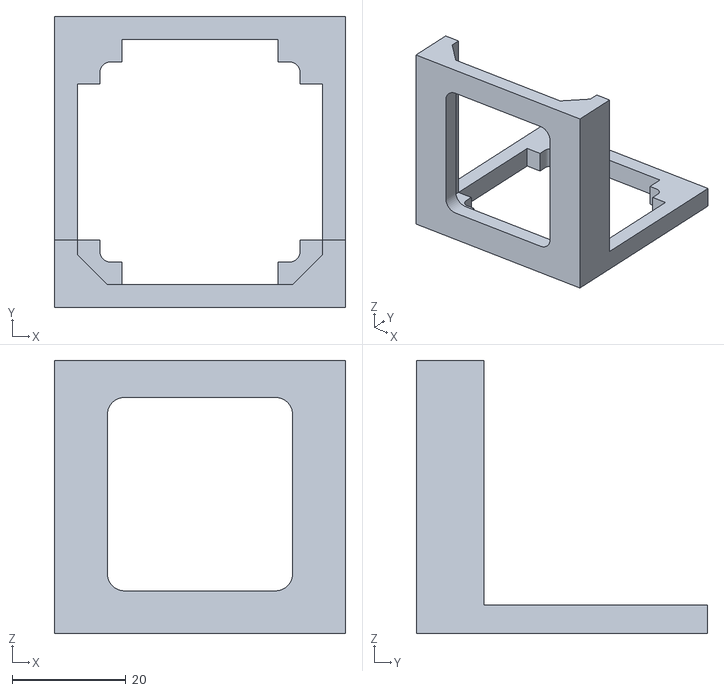
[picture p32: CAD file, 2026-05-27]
3D-Files/stl/MainBody_NemaHolder.stl
51.2 x 51.2 x 48.0

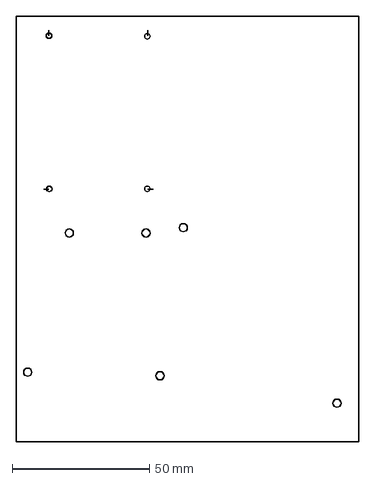
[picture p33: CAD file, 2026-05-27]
3D-Files/dxf/Swinger_Sheet.dxf
125.0 x 155.0 mm

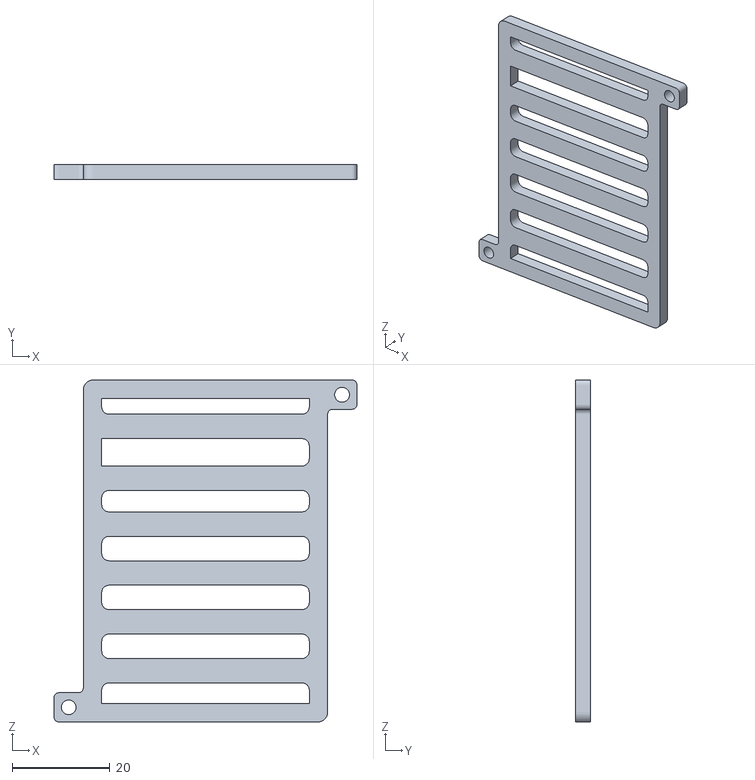
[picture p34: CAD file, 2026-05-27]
3D-Files/stl/Swinger_BMSBoxBottom.stl
62.0 x 3.00 x 70.0

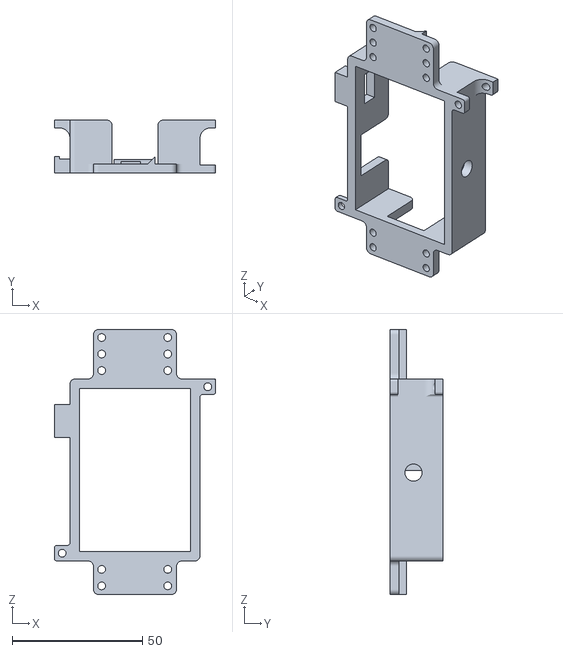
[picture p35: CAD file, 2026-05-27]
3D-Files/stl/Swinger_BMSBoxBox.stl
62.0 x 20.3 x 101.9

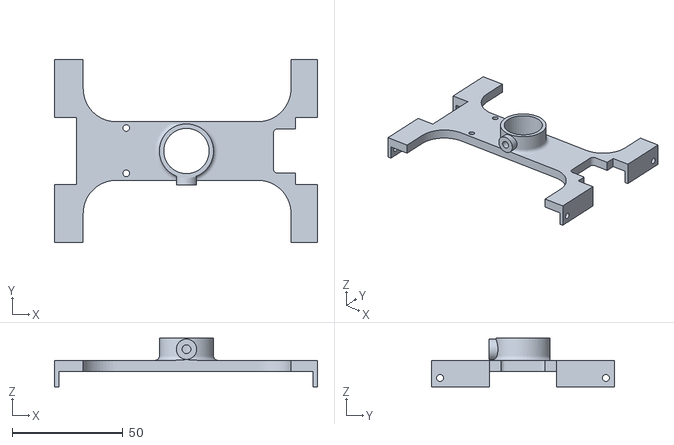
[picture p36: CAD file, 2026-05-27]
3D-Files/stl/Poll_BodyAttachement.stl
119.0 x 83.0 x 22.0

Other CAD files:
3D-Files/dxf/Head_TopPlate.dxf
3D-Files/stl/Poll_MagnetHolder.stl
3D-Files/dxf/Head_TopPlateStepper.dxf
3D-Files/dxf/Head_TopPlateSides.dxf
3D-Files/stl/Axis_GearSecondPart.stl
3D-Files/stl/Axis_JunctionToJunction.stl
3D-Files/stl/Axis_JunctionWithSphere.stl
3D-Files/stl/Axis_Rode.stl
3D-Files/stl/Axis_StopRing.stl
3D-Files/stl/Head_BallBearingStopper.stl
3D-Files/stl/Head_BottomPartLid.stl
3D-Files/stl/Head_BottomPlate.stl
3D-Files/stl/Head_ESP32HolderBackSide.stl
3D-Files/stl/Head_ESP32HolderFrontSide.stl
3D-Files/stl/Head_GearBottomPlate.stl
3D-Files/stl/Head_GearForStepper.stl
3D-Files/stl/Head_Manchette.stl
3D-Files/stl/Head_TopPartLid.stl
3D-Files/stl/MainBody_NemaHolderScrewed.stl
3D-Files/stl/Sphere-Bone.stl
3D-Files/stl/Sphere-TopYellowPart.stl
3D-Files/stl/Sphere_Cap.stl
3D-Files/stl/Sphere_Equator.stl
3D-Files/stl/Sphere_Lid.stl
3D-Files/stl/Sphere_LidSurrounding.stl
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

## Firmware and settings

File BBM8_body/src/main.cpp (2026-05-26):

#include <Arduino.h>
#include "StateEstimator.hpp"
#include "RollController.hpp"
#include "DriveController.hpp"
#include "Telemetry.hpp"

// ---- Config ----
constexpr int SERVO_PIN = 18;
constexpr int STEP_PIN = 25;
constexpr int DIR_PIN  = 26;
constexpr int ENABLE_PIN = 17;
constexpr uint32_t CONTROL_LOOP_MS = 50;       // 20 Hz control loop
constexpr uint32_t TELEMETRY_INTERVAL_MS = 100; // 10 Hz telemetry rate

// ---- Roll PID gains (!!! TO TUNE !!!) ----
constexpr float KP_ROLL = 0.9f;
constexpr float KI_ROLL = 0.0f;
constexpr float KD_ROLL = 0.0f;

// Max stepper speed in steps/second
// max robot speed = MAX_STEPPER_SPEED / ((STEPS_PER_REV * GEAR_RATIO) / (SPHERE_DIAMETER_M * PI))
//                 = 1300 / ((200 * 6.667) / (0.35 * PI)) ≈ 1.07 m/s
constexpr float MAX_STEPPER_SPEED = 1300.0f;

// ---- Complementary filter coefficient (!!! TO TUNE !!!) ----
// 0.98 = trust gyro 98% short-term, correct with accel 2% long-term
constexpr float ALPHA = 0.98f;

// ---- Safety ----
volatile bool STOP = true; // Start in stopped mode for safe start

// ---- Module instances ----
StateEstimator state(ALPHA);
RollController rollCtrl(KP_ROLL, KI_ROLL, KD_ROLL, SERVO_PIN);
DriveController driveCtrl(MAX_STEPPER_SPEED, STEP_PIN, DIR_PIN, ENABLE_PIN);
Telemetry      telemetry;

// ---- Telemetry snapshot (Core 1 writes, Core 0 reads) ----
struct TelSnap {
    float roll, pitch, rollTarget, rollOutput, rollErr, rollIntegral, rollDerivative, driveSpeed;
} telSnap;
portMUX_TYPE snapMux = portMUX_INITIALIZER_UNLOCKED;

// ---- Core 1: real-time control (20 Hz) ----
void controlTask(void*) {
    TickType_t lastWake = xTaskGetTickCount();
    constexpr float dt = CONTROL_LOOP_MS / 1000.0f;

    while (true) {
        state.update(dt);

        if (!STOP) {
            rollCtrl.update(state.getRoll(), dt);
            driveCtrl.update(state.getPitch());
        } else {
            driveCtrl.setTargetSpeed(0.0f);
            driveCtrl.stopMove();
            // Serial.println("---- STOPPED ----");
        }

        portENTER_CRITICAL(&snapMux);
        telSnap = {
            state.getRoll(),
            state.getPitch(),
            rollCtrl.getTarget(),
            rollCtrl.pid().getLastOutput(),
            rollCtrl.pid().getLastError(),
            rollCtrl.pid().getIntegral(),
            rollCtrl.pid().getLastDerivative(),
            driveCtrl.getTargetSpeed()
        };
        portEXIT_CRITICAL(&snapMux);

        vTaskDelayUntil(&lastWake, pdMS_TO_TICKS(CONTROL_LOOP_MS));
    }
}

// ---- Core 0: telemetry send (10 Hz), co-located with WiFi stack ----
void telemetryTask(void*) {
    TickType_t lastWake = xTaskGetTickCount();

    while (true) {
        TelSnap snap;
        portENTER_CRITICAL(&snapMux);
        snap = telSnap;
        portEXIT_CRITICAL(&snapMux);

        Serial.println("---- sending telemetry ----");
        telemetry.sendTelemetry(
            snap.roll, snap.pitch,
            snap.rollTarget, snap.rollOutput,
            snap.rollErr, snap.rollIntegral,
            snap.rollDerivative, snap.driveSpeed
        );

        vTaskDelayUntil(&lastWake, pdMS_TO_TICKS(TELEMETRY_INTERVAL_MS));
    }
}

void setup() {
    Serial.begin(115200);

    while (!state.begin()) {
        Serial.println("[ERROR] MPU-9250 not found. Check wiring.");
    }
    Serial.println("[OK] MPU-9250 initialised.");

    rollCtrl.begin();
    Serial.println("[OK] RollController ready.");
    driveCtrl.begin();
    Serial.println("[OK] DriveController ready.");

    telemetry.onTargetChanged([](float targetDeg) {
        rollCtrl.setTarget(targetDeg);
    });
    telemetry.onRollGainsChanged([](float kp, float ki, float kd) {
        rollCtrl.pid().setGains(kp, ki, kd);
    });
    telemetry.onDriveSpeedChanged([](float mPerSec) {
        driveCtrl.setTargetSpeed(mPerSec);
    });
    telemetry.onStopChanged([](bool stop) {
        STOP = stop;
    });
    telemetry.onPitchLimiterChanged([](bool enabled, float maxDeg) {
        driveCtrl.setPitchLimiterEnabled(enabled);
        driveCtrl.setMaxPitchDeg(maxDeg);
    });
    telemetry.begin();

    xTaskCreatePinnedToCore(controlTask,   "ControlTask",   4096, NULL, 5, NULL, 1);
    xTaskCreatePinnedToCore(telemetryTask, "TelemetryTask", 4096, NULL, 3, NULL, 0);
    vTaskDelete(NULL); // delete Arduino init task — tasks are now running
}

void loop() {}

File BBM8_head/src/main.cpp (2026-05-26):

#include <Arduino.h>
#include <WiFi.h>
#include <esp_now.h>
#include "Telemetry.hpp"
#include "EspNowPackets.hpp"
#include "EspNowConfig.hpp"
#include "Camera.hpp"
#include "HeadRotation.hpp"

Telemetry telemetry;

// Mirrors the browser's stopped flag so we can re-send it after a body reset.
static volatile bool     s_stopped              = true;
static volatile bool     s_pitchLimiterEnabled  = false;
static volatile float    s_maxPitchDeg          = 20.0f;
static volatile uint32_t s_lastTelemMs          = 0;
static bool              s_bodyLost             = true;  // true until first telemetry arrives

// ── ESP-NOW: send a CommandPacket to the body ────────────────────────────────
static void sendCommand(const CommandPacket& cmd) {
    esp_now_send(BODY_MAC, reinterpret_cast<const uint8_t*>(&cmd), sizeof(cmd));
}

// ── ESP-NOW: receive TelemetryPacket from body ───────────────────────────────
void onEspNowRecv(const uint8_t* /*mac*/, const uint8_t* data, int len) {
    if (len < static_cast<int>(sizeof(TelemetryPacket))) return;
    const auto* pkt = reinterpret_cast<const TelemetryPacket*>(data);
    if (pkt->type != PacketType::TELEMETRY) return;

    // If body was lost (reset/brownout), push current state so it syncs.
    if (s_bodyLost) {
        CommandPacket sync{};
        sync.cmdType = CMD_STOP;
        sync.stop    = s_stopped ? 1u : 0u;
        sendCommand(sync);

        CommandPacket pitchSync{};
        pitchSync.cmdType = CMD_PITCH_LIMITER;
        pitchSync.stop    = s_pitchLimiterEnabled ? 1u : 0u;
        pitchSync.target  = s_maxPitchDeg;
        sendCommand(pitchSync);

        s_bodyLost = false;
    }
    s_lastTelemMs = millis();

    telemetry.forwardTelemetry(*pkt);
}

void setup() {
    Serial.begin(115200);

    // Wire browser commands → ESP-NOW sends to body.
    telemetry.onTargetChanged([](float t) {
        CommandPacket cmd{};
        cmd.cmdType = CMD_TARGET;
        cmd.target  = t;
        sendCommand(cmd);
    });
    telemetry.onRollGainsChanged([](float kp, float ki, float kd) {
        CommandPacket cmd{};
        cmd.cmdType = CMD_ROLL_GAINS;
        cmd.rollKp  = kp;
        cmd.rollKi  = ki;
        cmd.rollKd  = kd;
        sendCommand(cmd);
    });
    telemetry.onDriveSpeedChanged([](float v) {
        CommandPacket cmd{};
        cmd.cmdType    = CMD_DRIVE_SPEED;
        cmd.driveSpeed = v;
        sendCommand(cmd);
    });
    telemetry.onStopChanged([](bool s) {
        s_stopped = s;
        CommandPacket cmd{};
        cmd.cmdType = CMD_STOP;
        cmd.stop    = s ? 1u : 0u;
        sendCommand(cmd);
    });
    telemetry.onHeadRotateChanged([](int steps) {
        headRotation_step(steps);
    });
    telemetry.onPitchLimiterChanged([](bool enabled, float maxDeg) {
        s_pitchLimiterEnabled = enabled;
        s_maxPitchDeg         = maxDeg;
        CommandPacket cmd{};
        cmd.cmdType = CMD_PITCH_LIMITER;
        cmd.stop    = enabled ? 1u : 0u;
        cmd.target  = maxDeg;
        sendCommand(cmd);
    });

    // begin() starts softAP on ESPNOW_CHANNEL, then esp_now_init, then HTTP + WebSocket.
    telemetry.begin();

    if (camera_init())
        camera_stream_begin();

    headRotation_init();
    headRotation_begin();

    // Register body as ESP-NOW peer (for outgoing CommandPackets).
    esp_now_peer_info_t peer{};
    memcpy(peer.peer_addr, BODY_MAC, 6);
    peer.channel = ESPNOW_CHANNEL;
    peer.encrypt = false;
    if (esp_now_add_peer(&peer) != ESP_OK) {
        Serial.println("[HEAD] Failed to add body peer.");
    }

    // Register callback for incoming TelemetryPackets from body.
    esp_now_register_recv_cb(onEspNowRecv);

    Serial.printf("[HEAD] AP MAC: %s\n", WiFi.softAPmacAddress().c_str());
    Serial.println("[HEAD] Ready.");
}

void loop() {
    telemetry.update();
    if (!s_bodyLost && (millis() - s_lastTelemMs > 1000u))
        s_bodyLost = true;
}

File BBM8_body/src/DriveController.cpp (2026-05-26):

#include "DriveController.hpp"

DriveController::DriveController(float maxSpeed, int stepPin, int dirPin, int enablePin)
    : _engine(), _stepper(nullptr),
      _stepPin(stepPin), _dirPin(dirPin), _enablePin(enablePin),
      _maxSpeed(maxSpeed), _targetMPerSec(0.0f)
{}

void DriveController::begin() {
    _engine.init();
    _stepper = _engine.stepperConnectToPin(_stepPin);
    if (_stepper == nullptr) {
        Serial.println("[ERROR] DriveController: stepperConnectToPin failed");
        return;
    }
    _stepper->setDirectionPin(_dirPin);
    if (_enablePin >= 0) {
        _stepper->setEnablePin(static_cast<uint8_t>(_enablePin)); // active LOW (A4988 default)
        _stepper->setAutoEnable(true); // energize on move, de-energize when stopped
    }
    _stepper->setAcceleration(1500);
    _stepper->setSpeedInHz(0); // Intialized with zero speed
}

void DriveController::update(float pitchDeg) {
    if (_stepper == nullptr) return;

    float targetStepsPerSec = mPerSecToSteps(_targetMPerSec);
    // Apply pitch limiter
    float limited = applyPitchLimiter(targetStepsPerSec, pitchDeg);
    // Constrain to max speed
    if (limited >  _maxSpeed) limited =  _maxSpeed;
    if (limited < -_maxSpeed) limited = -_maxSpeed;

    if (fabs(limited) <= 20.0f) {
        _stepper->stopMove();
        return;
    }

    uint32_t absHz = static_cast<uint32_t>(fabsf(limited));
    _stepper->setSpeedInHz(absHz);
    if (limited > 0.0f)
        _stepper->runForward();
    else
        _stepper->runBackward();
}

float DriveController::stepsPerM() const {
    return (STEPS_PER_REV * GEAR_RATIO) / (SPHERE_DIAMETER_M * M_PI);
}

float DriveController::mPerSecToSteps(float mPerSec) const {
    return mPerSec * stepsPerM();
}

float DriveController::applyPitchLimiter(float speedCommand, float pitchDeg) {
    if (!_pitchLimiterEnabled) return speedCommand;
    float factor = constrain(1.0f - abs(pitchDeg) / _maxPitchDeg, 0.0f, 1.0f);
    return speedCommand * factor;
}

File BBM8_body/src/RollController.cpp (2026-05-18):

#include "RollController.hpp"

RollController::RollController(float kp, float ki, float kd, int servoPin)
    : _pid(kp, ki, kd, -20.0f, 20.0f),
      _servoPin(servoPin),
      _targetDeg(0.0f)
{}

void RollController::begin() {
    _servo.attach(_servoPin);
    _servo.write(90);  // Neutral position on startup
}

void RollController::update(float rollDeg, float dt) {
    float correction = _pid.compute(_targetDeg, rollDeg, dt);

    // PID output is -90..+90 deg correction
    // servo.write() expects 0..180 (90 = neutral)
    int servoAngle = constrain(90 + (int)correction, 0, 180);
    _servo.write(servoAngle);
}

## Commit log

2026-04-02 projects template for the 2 micro-controller boards
2026-04-12 SE using IMU + PID for roll + WiFI Telemetry with Dashboard
2026-04-16 last PID output in dashboard + lighter theme for clarity
2026-04-16 correction of sign error in SE + tuning of alpha
    [StateEstimator.cpp, main.cpp]
2026-04-21 small fixes and tuning
    [RollController.cpp, StateEstimator.cpp, main.cpp]
2026-04-21 pins for the stepper in main
2026-04-26 updated default PID gains
2026-04-26 STOP button for safety (main loop not running when set to true)
2026-04-30 DriveController simplified (no PID)
2026-05-06 DriveController validated + small fix in SE
    [DriveController.cpp, StateEstimator.cpp, main.cpp]
2026-05-11 camera feedback on dashboard
2026-05-12 added motor control for head rotations
2026-05-12 Updated index.html. The old version doesn't have the camera stream nor the additional panels
2026-05-22 Adding further information to the list of materials
2026-05-22 Added the 3D folders and and some stl files
    [Head_BottomPartLid.stl, Head_BottomPlate.stl, Head_GearForStepper.stl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]
2026-05-22 README: continued the building of the heaad
    [Head_BallBearingStopper.stl, Head_ESP32HolderBackSide.stl, Head_ESP32HolderFrontSide.stl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]
2026-05-22 gear ratio update
2026-05-25 Changed the path to the stl file, since there was an issue
2026-05-25 sign change + no print spam
2026-05-26 fix stop bug when ESP reset
    [main.cpp]
2026-05-26 Added stl files of the sphere, started writing the instructions for it.
    [Sphere-Bone.stl, Sphere-TopYellowPart.stl, Sphere_Cap.stl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]
2026-05-26 Revise README with main body and building instructions
    Updated section titles and added details about building the mechanical part, including materials and instructions.
2026-05-26 option to disable pitch limiter + change max pitch
2026-05-27 fix of the name of dxf directory
    [Head_TopPlate.dxf, Head_TopPlateSides.dxf, Head_TopPlateStepper.dxf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]
2026-05-27 More stl files
    [Axis_GearMainPart.stl, Axis_GearSecondPart.stl, Axis_JunctionToJunction.stl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]
2026-05-27 Full axis build description, and a few more images and stl files
    [Axis_Rode.stl]
2026-05-27 Main body explanation + some stl files + some illustration files
    [MainBody_IMUHolder.stl, MainBody_NemaHolderScrewed.stl, MainBody_NemaHolderShaft.stl]
2026-05-27 Added the rest of whats needed for the interior body assembly, so main body, axis, poll, and the final assembly, and a lot of screenshots and stl files
    [MainBody_GearShaft.stl, Poll_BodyAttachement.stl, Poll_MagnetHolder.stl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]
2026-05-28 Added the step file of the full assembly
2026-05-28 filled BOM gaps, fixed typos, added swinger electronics, flashed guide and dashboard docs
2026-05-28 adding the BB-M8 illustration, and the electronic advise for the management of the cables
